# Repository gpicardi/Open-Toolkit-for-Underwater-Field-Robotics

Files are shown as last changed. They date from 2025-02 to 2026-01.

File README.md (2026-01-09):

# Open-Source Toolkit for Underwater Manipulation and Bio-inspired Robotics

## Overview

The **Open-Source Toolkit for Underwater Manipulation and Bio-inspired Robotics** is designed to facilitate the development of underwater robotic manipulators and legged systems. It provides modular, cost-effective, and open-source solutions for waterproofing, control, power management, and software integration, enabling researchers and developers to prototype and test underwater robotic systems more efficiently.

### Key Features
- **Waterproof Canisters**: Designed for Dynamixel actuators, tested up to 30m depth.
- **Control & Power Management**: Custom electronics enabling efficient underwater operations.
- **Leakage Detection System**: Early warning system for water ingress.
- **ROS 2-Based Software Stack**: Facilitates control, sensing, and actuation.
- **Open-Source Design**: Hardware and software available for community contributions.

## System Components

### 1. Underwater Robotic Joint
- Uses **Dynamixel XM430-W350** servo motors enclosed in an aluminum canister.
- Includes a **capacitive humidity sensor** and **DHT11 temperature sensor** for early leakage detection.
- Designed with **O-ring sealing** and a **pressure relief plug** to maintain internal pressure stability.

<!--![Waterproof Actuation Module](git_images/CannisterV1.JPG)-->
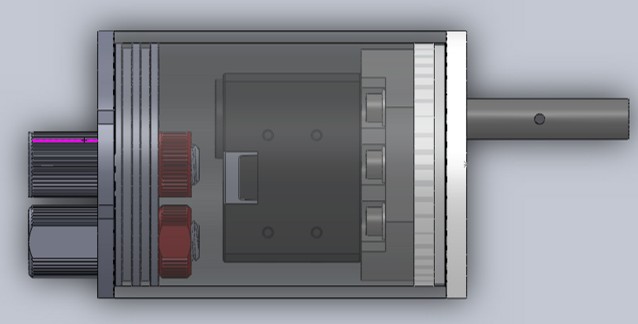
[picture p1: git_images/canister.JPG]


### 2. Control & Power Management
- Based on a **Raspberry Pi 4** architecture.
- Supports **RS485 communication** for Dynamixel servos.
- Includes **DCDC converters** for stable power delivery.
- Features integrated **humidity monitoring** for early fault detection.
- Compatible with Blue Robotics Canisters for integration.

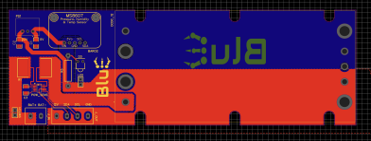
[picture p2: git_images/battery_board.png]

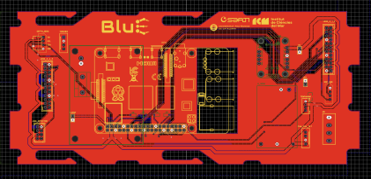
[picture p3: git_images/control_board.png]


### 3. ROS 2 Software Stack
- Modular software framework for motor control, sensing, and data acquisition.
- Supports real-time monitoring and logging.
- Facilitates integration with **networking and surface communication**.

## Experimental Validation

### 1. Leakage Detection Tests
- Humidity sensor successfully detected small water ingress during controlled tests.
- **Failure-depth tests**: Several trials conducted at different depths, with minor failures recorded at **Calabria 2021** and **La Spezia 2021**.

Leakage Detection Test

### 2. Structural and Environmental Tests
- FEM simulations in **SolidWorks** validated the canister’s buckling resistance.
- Field deployments in **real underwater conditions** for long-term monitoring.
- Potential future **hyperbaric chamber testing** to assess deeper water resistance.

Structural Testing

## Applications

### 1. **Leg Module for SILVER2**
- An **RRR serial manipulator** based on three underwater robotic joints.
- Integrated as the **legged system** for SILVER2.

SILVER2 Leg Module

### 2. **Tendon-Driven Actuation**
- Used for **soft robotic grippers** requiring flexible motion.
- Features a **spooling system** for precise cable-driven control.

Tendon-Driven Actuation

### 3. **Underactuated Mechanisms for Sampling**
- Designed for **sediment collection** in underwater environments.
- Utilizes a **four-bar linkage mechanism** for efficient grasping and storage.

Underactuated Sampling System

## Open Science & Reproducibility

To foster collaboration and reproducibility, all hardware designs, software, and datasets are shared under open licenses:
- **GitHub Repository**: [Link to repository]
- **Zenodo Archive**: [DOI for dataset & experiments]

We encourage contributions, modifications, and feedback to improve the toolkit and extend its capabilities for broader underwater robotics applications.

## Citing this Repository

If you use this toolkit in your research or project, please cite it as follows:

```
@misc{OpenFieldRoboticToolkit,
  author = {G. Picardi, S., M. Carandell, J.Aguirregomezcorta, M. Chellpurath, J. del Rio, M. Calisti, and J. Aguzzi},
  title = {Open Toolkit for Underwater Field Robotics},
  year = {2025},
  url = {[https://github.com/your-repo](https://github.com/gpicardi/Open-Toolkit-for-Underwater-Field-Robotics/)}
}
```

## Future Work
- Scaling for deeper environments beyond 30m.
- Integration of **AI-driven control strategies** for adaptive locomotion.
- Exploring bio-inspired legged movement for improved seabed interaction.
- Enhancing modularity for broader use cases in oceanographic research.

---
For more information, contact: **Giacomo Picardi giacomo.picardi1991@gmail.com or gpicardi@icm.csic.es**

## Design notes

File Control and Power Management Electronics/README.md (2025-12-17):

# Control and Power Management Electronics

## Overview

This repository documents the **control and power management electronics** design of the **Open Toolkit for Underwater Robotics**. The focus is on providing robust, modular, and efficient electronic control systems suitable for underwater robotics applications. The **Main board** folder and the **Battery board** folders respectively contain a csv file with the Bill Of Material (BOM), a pdf file with the electrical scheme, and two compressed folder with 3D and gerber files for visualization in electronics CAD and manufacturing the PCBs. Both PCBs have been dimensioned to fit into standard watertight enclosures add_dimensions (https://bluerobotics.com/store/watertight-enclosures/wte-vp/).

## Electronics and Power Management System

### 1. Control Board
- Based on **Raspberry Pi 4** architecture.
- Supports **RS485 communication** for **Dynamixel** actuators.
- Provides interface for the following sensor devices: BNO055 **IMU**, DHT11 **temperature and humidity sensors**, ltc2945 **power monitor**, DHT11 **temperature and humidity sensor**, ms8607 **external pressure sensor**.
- Provides interface for **PWM devices** such as torches, servomotors
- Supports 12V power input and it integrated a **DCDC converter** to supply **5V**

Control Board

### 2. Power Management Board
- Regulates power supply for **motors, sensors, and communication devices**.
- Supports up to **24V power input** from battery, designed to work with a 12V 25Ah DC lithium polymer battery*.
- Includes i2c line to for internal **pressure, temperature and humidity sensor MS5837** .

Power Management Board

## List of Components

| Component | Specification | Function |
|---|---|---|
| Single board computer | Raspberry Pi 4 | Controls all robotic operations |
| IMU | BNO055 | 9 DOF IMU with fused absolute orientation | Raw accelerations, angular velocities, magnetic field and fused absolute orientation
| Humidity and temperature sensor | DHT11 | Early leakage detection within control and motor canisters |
| Power monitor | LTC2945 | Monitoring Voltage, Current and Power consumption  |
| Pressure, humidity and temperature sensor | MS5837 | Early leakage detection within battery canister |
| External pressure and temperature sensing | MS8607 | External temperature and pressure for depth estimation |

## Discussion & Tips
Any other interesting point or tips for improvements can go here

## Future Improvements
Same.

---
For more information, contact: **Giacomo Picardi giacomo.picardi1991@gmail.com or gpicardi@icm.csic.es** or **Matias Carandell mail**

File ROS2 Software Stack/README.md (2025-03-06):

# ROS2 Software Stack

## Disclaimer
To be ported from BluE repository 

## Overview

This repository documents the **ROS2 Software Stack** used in the **Open Toolkit for Underwater Robotics**. The software provides modular control for underwater robotic joints, sensors, and communication interfaces, leveraging ROS2 for distributed and scalable operation.

## Software Architecture

The ROS2 software stack includes:
- **Sensor Nodes** for real-time data acquisition.
- **Motor Control and State Feedback using ros2_control** for efficient motion execution.
- **Communication Interfaces** for networked operations (e.g. with a control PC, surface buoy, or fixed platform). 

## Sensor Nodes

### 1. **Humidity and Temperature Sensor Node**
- **Sensor Used**: DHT11
- **Description**: Monitors the internal canister conditions to detect early leakage or overheating.
- **Topic Published**: `/dht11_sensor_data` (rrr_interfaces/msg/DhtSensorData)
- **Data Format**:
  ```\
  std_msgs/String location
  std_msgs/Float64 temperature
  std_msgs/Float64 humidity
  ```

### 2. **IMU Node (Inertial Measurement Unit)**
- **Sensor Used**: BNO055
- **Description**: Provides real-time orientation, acceleration, and angular velocity for state estimation.
- **Topic Published**: `/imu/data` (sensor_msgs/msg/Imu)
- **Reference Repository**: https://github.com/flynneva/bno055

### 3. **Internal Pressure, Temperature and Humidity Sensor Node**
- **Sensor Used**: MS8607
- **Description**: Measures pressure, temperature and humidity inside the control canister.
- **Topic Published**: 
  - `/ms8607/pressure` (std_msgs/Float64)
  - `/ms8607/temperature` (std_msgs/Float64)
  - `/ms8607/humidity` (std_msgs/Float64)

### 4. **External Pressure, Temperature and Depth Sensor Node**
- **Sensor Used**: MS8537
- **Description**: Measures underwater pressure, temperature and depth.
- **Topic Published**:
  - `/ms8537/pressure` (std_msgs/Float64)
  - `/ms8537/temperature` (std_msgs/Float64)
  - `/ms8537/depth` (std_msgs/Float64)

### 5. **Powering Monitor Sensor Node**
- **Sensor Used**: LTC2945
- **Description**: Measures power monitoring.
- **Topic Published**:
  - `/ltc2945/vin` (std_msgs/Float64)
  - `/ltc2945/power` (std_msgs/Float64)
  - `/ltc2945/current` (std_msgs/Float64)

## Motor Control with `ros2_control`

The **ros2_control** framework is used for real-time motor actuation.

### 1. **Hardware Interface**
- **Driver Used**: Dynamixel Workbench (RS485 communication) https://github.com/dynamixel-community/dynamixel_hardware.
- **XML RRR_Manipulator Xacro File**: Simple transmission mechanism added to set offset and reduction of the Dynamixel Actuators
```xml
<transmission name="coxa_transmission">
  <plugin>transmission_interface/SimpleTransmission</plugin>
  <actuator name="coxa_actuator" role="coxa_actuator"/>
  <joint name="coxa_joint" role="coxa_joint">
      <mechanical_reduction>${coxa_reduction}</mechanical_reduction>
      <offset>${coxa_offset}</offset>
  </joint>
</transmission>
```
### 2. **Controller Configuration**
A sample `ros2_control` configuration for the motor driver:
```yaml
controller_manager:
  ros__parameters:
    update_rate: 30

    joint_state_broadcaster:
      type: joint_state_broadcaster/JointStateBroadcaster

    forward_position_controller:
      type: forward_command_controller/ForwardCommandController

    joint_trajectory_position_controller:
      type: joint_trajectory_controller/JointTrajectoryController

forward_position_controller:
  ros__parameters:
    joints:
      - coxa_joint
      - femur_joint
      - tibia_joint

    interface_name: position

    action_monitor_rate: 20.0

    allow_partial_joints_goal: false
    open_loop_control: true
    allow_integration_in_goal_trajectories: true
    constraints:
      stopped_velocity_tolerance: 0.01
      goal_time: 0.0

```

### 3. **Motor Control Execution**
- Position commands are sent via `/forward_position_controller/commands`. I.e.:
  ```
  ros2 topic pub --once /forward_position_controller/commands std_msgs/msg/Float64MultiArray "data: - 0.75 - 0.8 - 2.3"

  ros2 topic pub --once /forward_position_controller/commands std_msgs/msg/Float64MultiArray "{data:  [2.0, 2.0, 2.0]}"
  ```
- Position-based control can be implemented via `/motor/position`.
- State feedback (position, velocity, effort) is provided via `/joint_states`.

### 4. RRR Manipulator Application
- The toolkit is applied to the case of an RRR serial manipulator.
- Robot description and controller configuration are contained in the /rrr_manipulator package.
- Replace such directory with your own description in order to test your own robot implementation.
---
For more information, contact:
- **Giacomo Picardi: giacomo.picardi1991@gmail.com or gpicardi@icm.csic.es**
- **Jorge Aguirregomezcorta Aina: jaguirregomezcorta@gmail.com or jaguirregomezcorta@icm.csic.es**

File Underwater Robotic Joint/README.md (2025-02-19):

# Underwater Robotics joint

## Overview

This repository documents the mechanical design of the **Open Toolkit for Underwater Robotics**, providing details on the waterproof canisters, actuator integration, and material selection. The goal is to offer a reproducible, modular, and cost-effective approach to underwater robotic systems.

## Mechanical Subsystems

### 1. Waterproof Actuation Module
- Designed for **Dynamixel XM430-W350** actuators.
- Enclosed in a **6000-series aluminum** canister for corrosion resistance.
- Features a **double O-ring seal** and **pressure relief plug**.
- Includes **early leakage detection** with humidity and temperature sensors.



### 2. Structural Components
- Frame and mounting brackets designed for **submersion stability**.
- Components are **CNC machined** for precision.
- Stress analysis performed using **FEM simulations** in SolidWorks.

## Material Selection

| Component | Material | Justification |
|---|---|---|
| Canister | 6000-series Aluminum | Corrosion resistance, lightweight, machinable |
| Shaft | 316 Stainless Steel  | Prevents corrosion under prolonged exposure |
| Seals | Nitrile Rubber (NBR) | High resistance to water ingress |
| Front Cap | ABS Plastic | Good adhesion properties with aluminum |
| Structural Frame  | Anodized Aluminum | Increased durability in marine environments  |

## Discussion & Tips

### 1. **Canister Sealing Considerations**
- Ensure **O-rings are lubricated** before assembly.
- Avoid excessive tightening of **rear cap** to maintain proper compression.
- Periodically inspect the **humidity sensor readings** for early leakage detection.

### 2. **Structural Strength & Buoyancy**
- Consider **reducing metal thickness** to minimize weight without compromising depth resistance.
- Add **buoyancy foam** for neutral buoyancy in deeper deployments.
- FEM analysis suggests **reinforcement** at stress points in the leg modules.

### 3. **Corrosion Prevention**
- **Rinse components with fresh water** after deployment.
- Use **anodized finishes** or protective coatings on aluminum surfaces.
- Regularly inspect and replace **rubber seals** to maintain watertight integrity.

## Future Improvements
- **Optimizing shaft seals** to reduce potential lateral leaks.
- **Exploring new materials** like titanium for deeper applications.
- **Hyperbaric testing** to validate performance beyond 30m depth.

---
For more information, contact: **Giacomo Picardi giacomo.picardi1991@gmail.com or gpicardi@icm.csic.es** or **Saverio Iacoponi mail@mail**

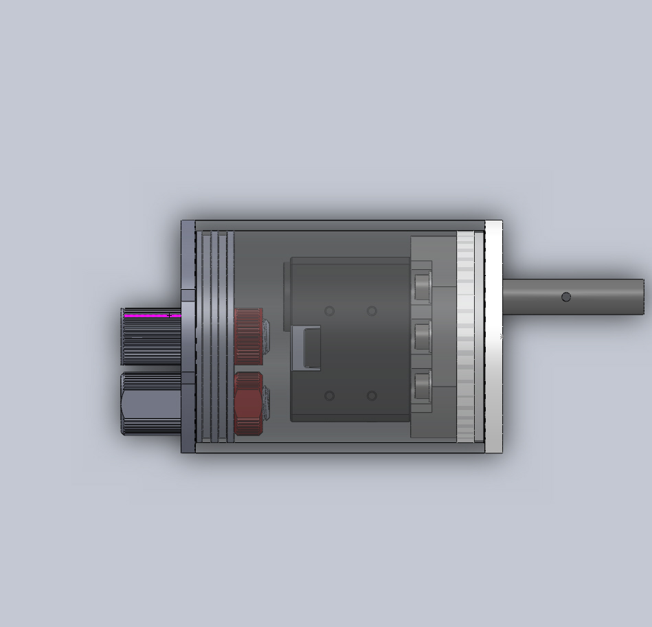
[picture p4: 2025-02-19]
git_images/CannisterV1.JPG

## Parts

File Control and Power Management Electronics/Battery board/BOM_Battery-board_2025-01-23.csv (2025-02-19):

ID | Name | Designator | Footprint | Quantity | Manufacturer Part | Manufacturer | Supplier | Supplier Part | Price | Pins | 3DModel | Contributor | JLCPCB Part Class | Package Display | description | link
1 | V28A12C200BL | DCDC_12 | V48A24C500BG | 1 |  |  |  |  |  | 9 |  | Simon
2 | 3mΩ | R1 | RES-SMD_L15.0-W7.7 | 1 | PU5931FKMP70R001L | YAGEO(国巨) | LCSC | C2079813 | 0.308 | 2 | RES-SMD_L15.0-W7.7 | lcsc | Extended Part |  |  | https://lcsc.com/eda_search?q=C2079813&%26type=1&ref=editor
3 | 173010542 | PS1 | 173010542 | 1 |  |  |  |  |  | 3 |  | FelipeRifo
4 | ADAFRUIT MS8607 PRESSURE HUMIDIT - edited | BARO2 | ADAFRUIT MS8607 | 1 | 4716 | Adafruit Industries LLC | Digi-Key | 1528-4716-ND |  | 7 |  | daniyal.ah3 |  |  |  | https://www.digikey.pt/products/en?keywords=%E2%80%8E1528-4716-ND%E2%80%8E
5 | 10uF | C1,C2 | 1206 | 2 | C1206C106K4RACAUTO | KEMET | LCSC | C141190 | 0.129 | 2 |  | LCSC |  | No
6 | 0.1uF | C3 | 1206 | 1 | C1206C106K4RACAUTO | KEMET | LCSC | C141190 | 0.129 | 2 |  | LCSC |  | No
7 | LED-1 | D3 | LED-TH_LED-DP2-2LED | 1 | 5600 | VccLite | Digi-Key | L20325-ND |  | 2 |  | sifa33752 |  |  |  | https://vcclite.com/product/5602f5-5v/
8 | DINKLE RHB02 | J_IN | DINKLE 2 PIN_2 | 1 | 2EHDR-02P | Dinkle | LCSC | C183509 |  | 2 |  | corykersey |  |  |  | https://lcsc.com/product-detail/Terminal-Blocks_2EHDR-02P_C183509.html
9 | NO | J_OUT | DINKLE 4 PIN_2 | 1 | 2EHDR-06P |  | LCSC | C165061 |  | 4 |  | corykersey |  |  |  | https://lcsc.com/product-detail/Terminal-Blocks_2EHDR-06P_C165061.html
10 | jumper | LED,SWITCH | JUMPER2 | 2 |  |  |  | MAX9934 |  | 2 |  | Matias Carandell |  |  | Jumper 2 Pin
11 | LTC2945IMS#TRPBF | POW_SENS | MSOP-12_L4.0-W3.0-P0.65-LS5.0-BL | 1 | LTC2945IMS#TRPBF | ADI(亚德诺)/LINEAR(凌特) | LCSC | C683689 | 7.671 | 12 | MSOP-12_L4.0-W3.0-H1.1-P0.65-LS4.9-BL | LCSC | Extended Part |  |  | https://lcsc.com/eda_search?q=C683689&%26type=1&ref=editor
12 | RESISTOR 5W | R3 | RESISTOR 2W | 1 |  |  |  |  |  | 2 |  | surajp1977

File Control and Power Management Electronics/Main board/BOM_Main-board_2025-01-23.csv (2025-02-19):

ID | Name | Designator | Footprint | Quantity | Manufacturer Part | Manufacturer | Supplier | Supplier Part | Price | Pins | 3DModel | Contributor | JLCPCB Part Class | Package Display | description | link
1 | 4PIN | TEMP&HUM1,TEMP&HUM2,TEMP&HUM3,TEMP&HUM4,TEMP&HUM6,TEMP&HUM7,TEMP&HUM5 | GROVE-2MM-4PIN-A/D | 7 |  |  |  | MAX9934 |  | 4 |  | Matias Carandell
2 | BM04B- | DEPTH_SENS | HUM_SENS2 | 1 | BM04B-GHS-TBT(LF)(SN) | JST | LCSC | C161692 | 0.169 | 10 |  | LCSC | Extended Part |  |  | https://lcsc.com/eda_search?q=C161692&%26type=1&ref=editor
3 | ADAFRUIT 9-DOF | IMU | ADAFRUIT BNO055 | 1 | Solid State Relays | Crydom | Adafruit |  |  | 14 |  | Daniel Sánchez
4 | TRACO POWER THM 15WI | DCDC_5 | TRACO POWER THM 15WI | 1 |  |  |  |  |  | 5 |  | longDiscoStick
5 | jumper | POW_DEPTH,POW_T&H,3.3RSP,J2,J4,J5,POW_IMU,POW_LEG,POW_TORCH | JUMPER2 | 9 |  |  |  | MAX9934 |  | 2 |  | Matias Carandell |  |  | Jumper 2 Pin
6 | 5PIN | IMU_SEL | 5PIN | 1 |  |  |  | MAX9934 |  | 5 |  | Matias Carandell
7 | NO | R1,R2,R3,R4 | RESISTOR-SMD-1206 | 4 |  |  | Banggood |  |  | 2 |  | WalterHaazen
8 | DINKLE RHB02 | J3,J1,J6 | DINKLE 2 PIN_2 | 3 | 2EHDR-02P | Dinkle | LCSC | C183509 |  | 2 |  | corykersey |  |  |  | https://lcsc.com/product-detail/Terminal-Blocks_2EHDR-02P_C183509.html
9 | 4PIN | SPI_SEL,I2C1_SEL,I2C2_SEL,TORCHES | TXRX | 4 |  |  |  | MAX9934 |  | 4 |  | Matias Carandell
10 | 22-03-5045 MOLEX | L2,L3,L4,L5,L6,L1,RSP_USB | MOLEX_22-03-5045 | 7 |  |  |  |  |  | 4 |  | Matias Carandell
11 | 3PIN | POW_BARO,PWM_TORCH | 3PIN | 2 |  |  |  | MAX9934 |  | 3 |  | Matias Carandell
12 | ADAFRUIT MS8607 PRESSURE HUMIDIT - edited | BARO1 | ADAFRUIT MS8607 | 1 | 4716 | Adafruit Industries LLC | Digi-Key | 1528-4716-ND |  | 7 |  | daniyal.ah3 |  |  |  | https://www.digikey.pt/products/en?keywords=%E2%80%8E1528-4716-ND%E2%80%8E
13 | 10uF | C1 | 1206 | 1 | C1206C106K4RACAUTO | KEMET | LCSC | C141190 | 0.129 | 2 |  | LCSC |  | No
14 | 8PIN | SIG_SEL,SIG_SEL2 | 8PIN | 2 |  |  |  | MAX9934 |  | 8 |  | Matias Carandell
15 | DINKLE RHB08 | JIN | DINKLE 4 PIN_2 | 1 | 2EHDR-06P |  | LCSC | C165061 |  | 4 |  | corykersey |  |  |  | https://lcsc.com/product-detail/Terminal-Blocks_2EHDR-06P_C165061.html
16 | RASPBERRY_PI_4_MODEL_B COPY | RPI1 | RASPBERRY_PI_4_MODEL_B | 1 | 2.54mm 2*20PFemale header | BOOMELE | LCSC | C50982 | 0.215 | 40 | HDR-TH_40P-P2.54-F-LI-2X20P | engeltronics | Extended Part
17 | CC6-2405SF-E | DCDC_3 | CC6-XXXXXF-E | 1 |  |  |  |  |  | 9 |  | Carlos Schelim

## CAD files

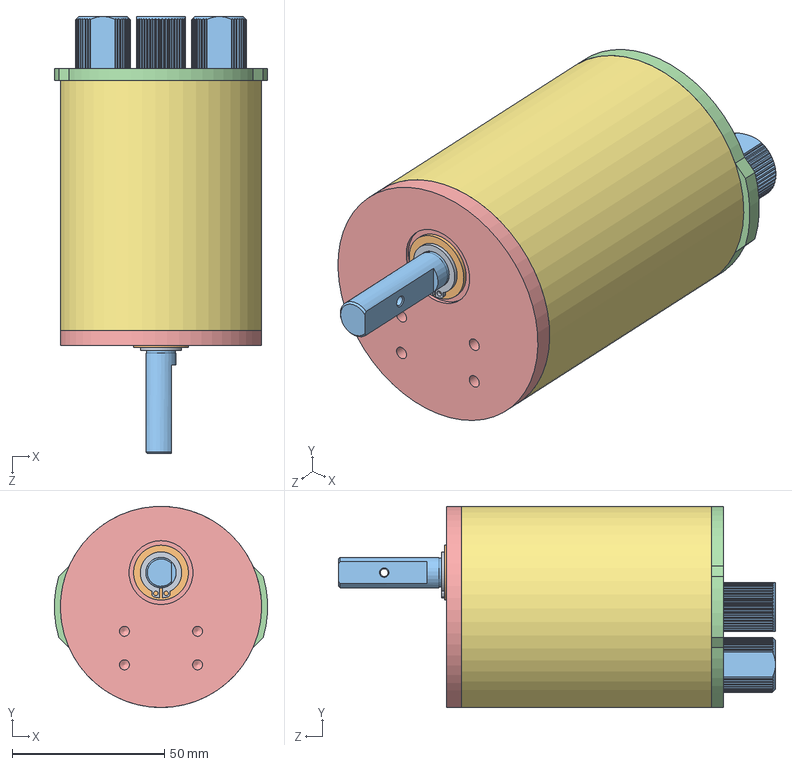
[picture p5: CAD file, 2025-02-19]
Underwater Robotic Joint/UW Robotic Joint Assembly SolidWorks/CannisterV1_new_version.SLDASM
69.9 x 66.0 x 143.4 mm
X-430_SPACER_RING x 8
X-430_CVR_CABLE
albero 2
mortor attachment
M2o5x10 x 2
M2o5x20 x 4
cannister cylinder
rondella M4 x 6
tappo frontale
tappo contatti
Penetrator 8mm x 3
WTM 1018 010
retention_ring_10mm

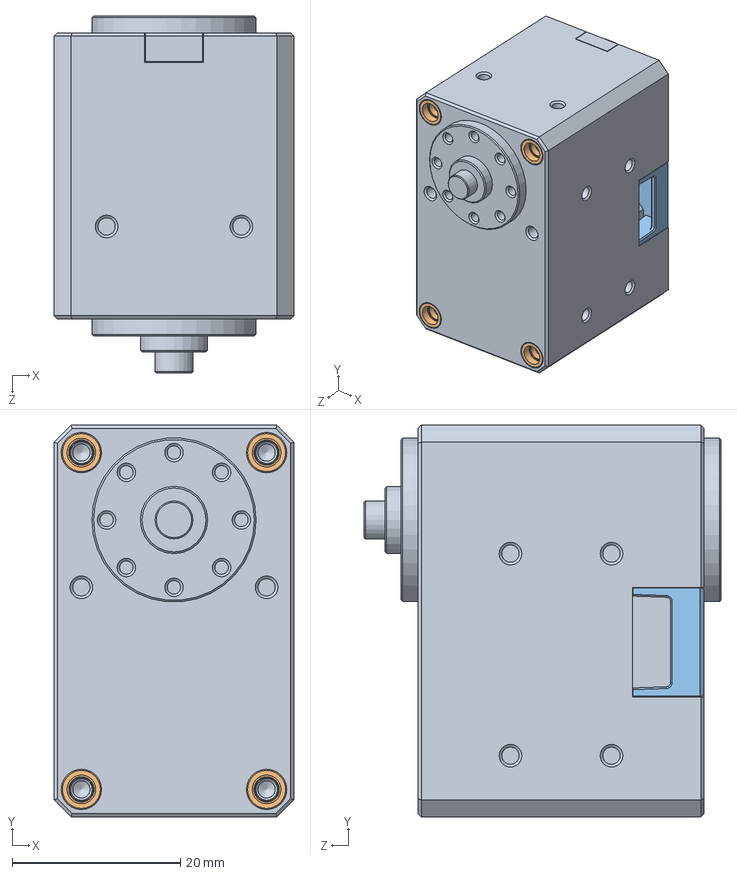
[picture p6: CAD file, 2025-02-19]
Underwater Robotic Joint/UW Robotic Joint Assembly SolidWorks/X-430_IDLE_20160516_ASM.sldasm
28.5 x 46.5 x 42.4 mm
X-430_IDLE
X-430_SPACER_RING x 8
X-430_CVR_CABLE

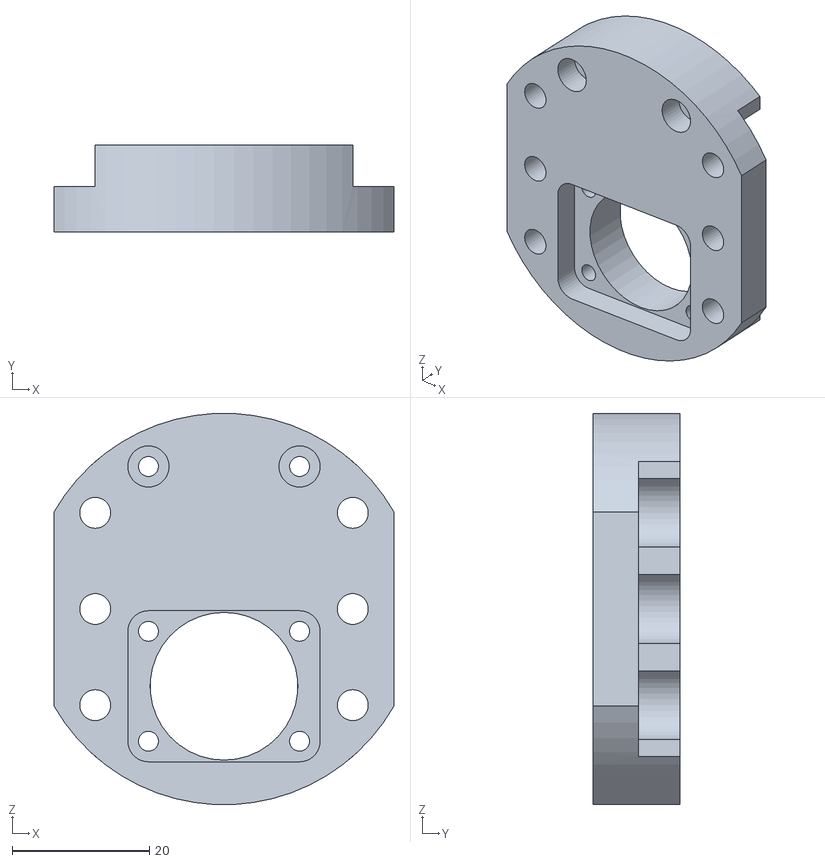
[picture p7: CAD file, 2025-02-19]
Underwater Robotic Joint/Underwater Robotic Joint Files for Manufacturing/mortor attachment.STL
49.5 x 12.6 x 56.9

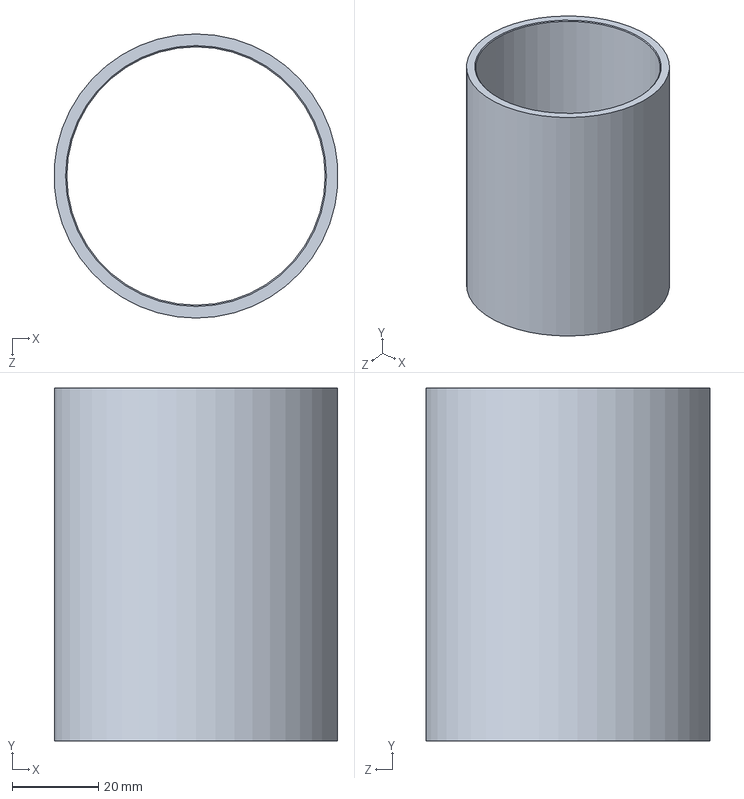
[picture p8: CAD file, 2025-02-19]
Underwater Robotic Joint/UW Robotic Joint Assembly SolidWorks/cannister cylinder.SLDPRT
65.8 x 82.0 x 66.0 mm

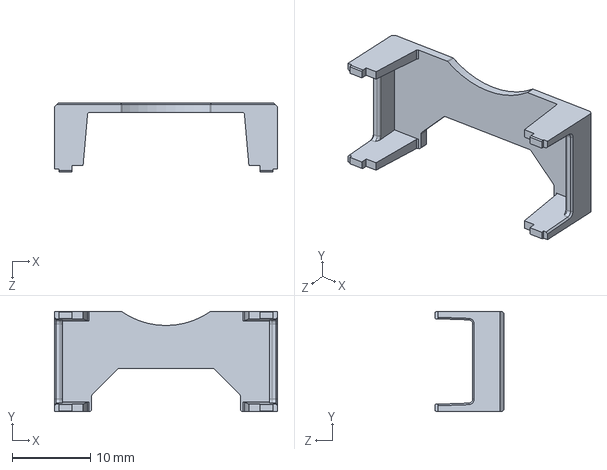
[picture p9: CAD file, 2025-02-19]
Underwater Robotic Joint/UW Robotic Joint Assembly SolidWorks/X-430_CVR_CABLE.sldprt
28.5 x 12.8 x 8.80 mm

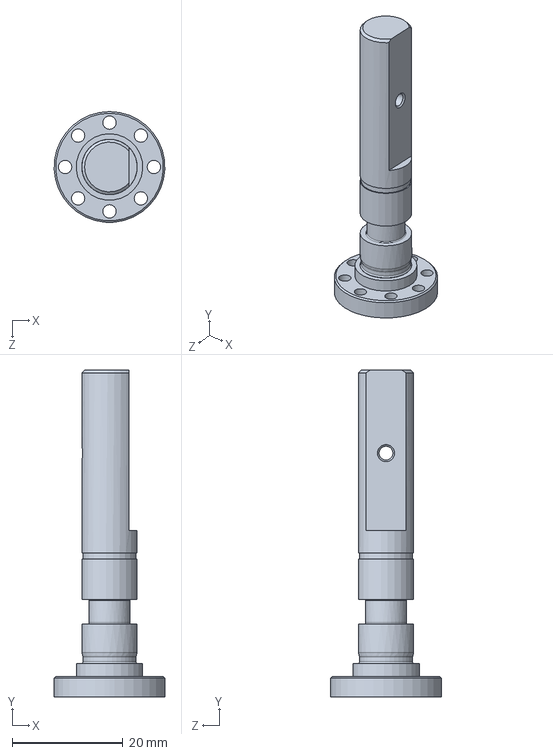
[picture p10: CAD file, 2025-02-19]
Underwater Robotic Joint/UW Robotic Joint Assembly SolidWorks/albero 2.SLDPRT
20.0 x 59.0 x 20.0 mm

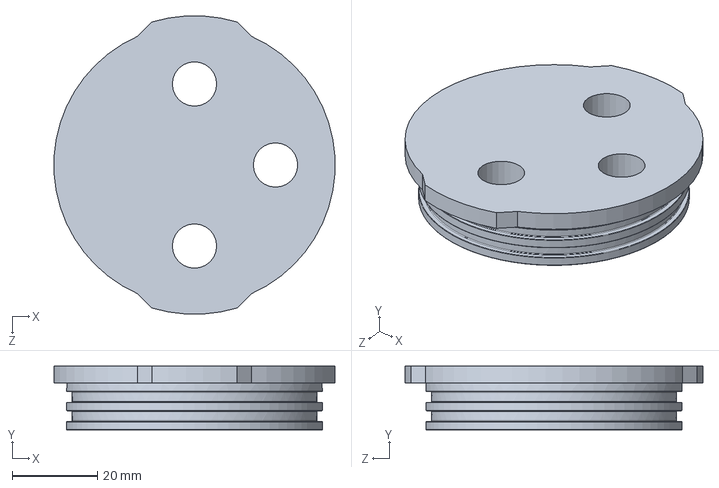
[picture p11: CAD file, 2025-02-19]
Underwater Robotic Joint/UW Robotic Joint Assembly SolidWorks/tappo contatti.SLDPRT
65.9 x 15.0 x 69.9 mm

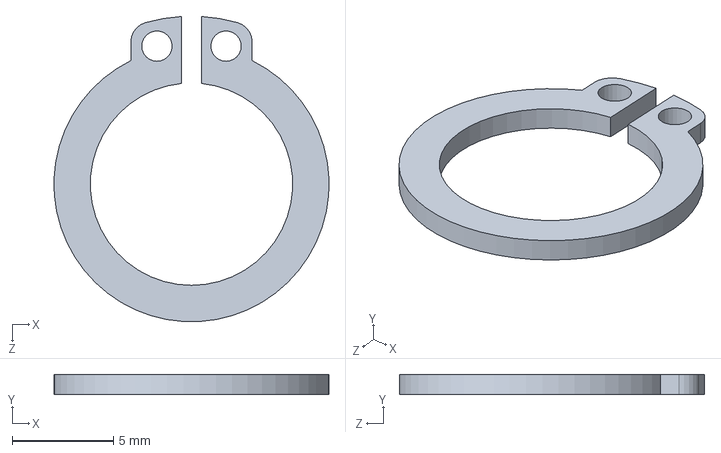
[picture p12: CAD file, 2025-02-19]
Underwater Robotic Joint/UW Robotic Joint Assembly SolidWorks/retention_ring_10mm.SLDPRT
13.6 x 1.00 x 15.1 mm

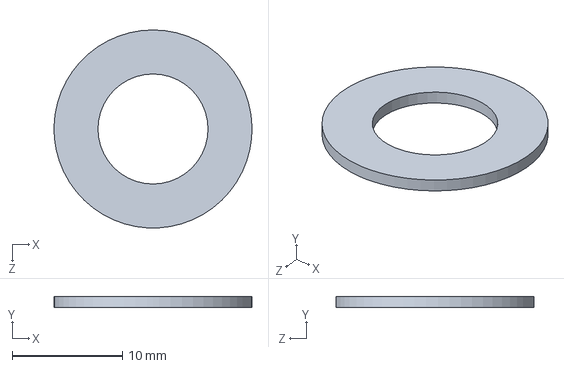
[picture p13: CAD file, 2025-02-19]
Underwater Robotic Joint/UW Robotic Joint Assembly SolidWorks/WTM 1018 010.SLDPRT
18.0 x 1.00 x 18.0 mm

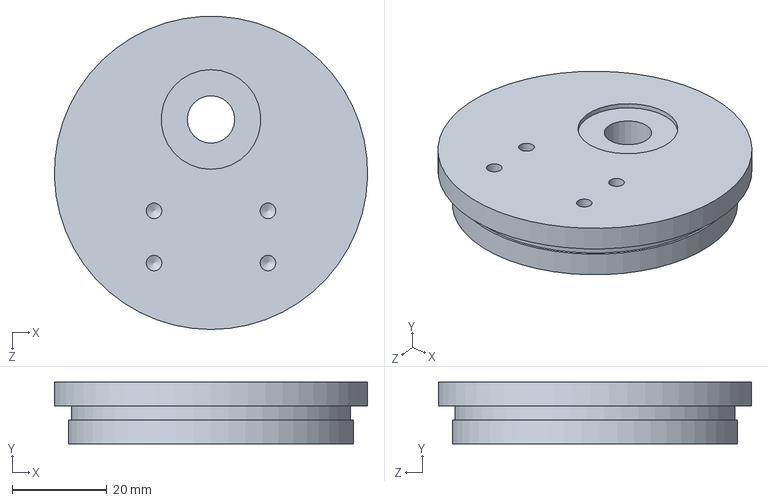
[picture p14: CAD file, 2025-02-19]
Underwater Robotic Joint/UW Robotic Joint Assembly SolidWorks/tappo frontale.SLDPRT
66.0 x 13.0 x 65.9 mm

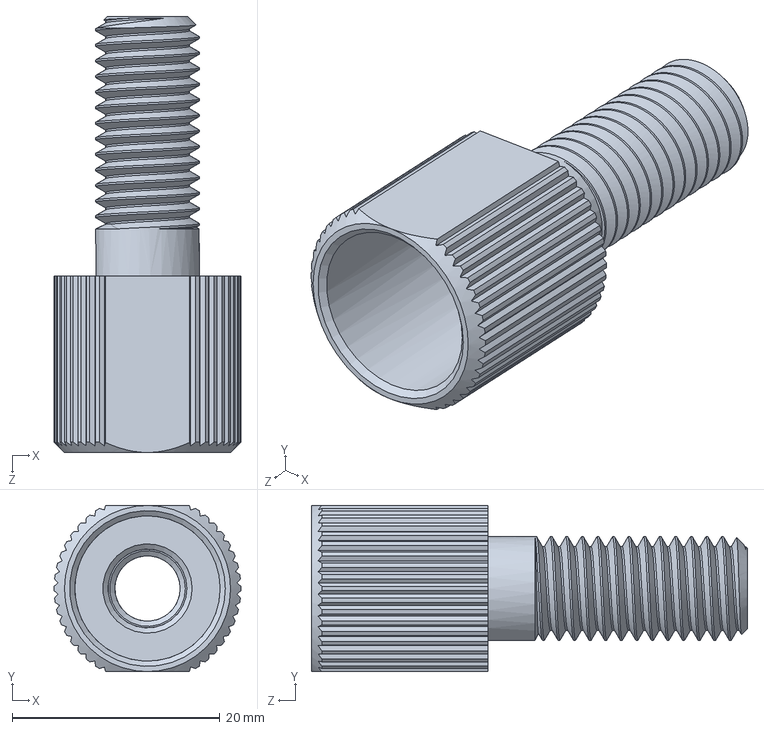
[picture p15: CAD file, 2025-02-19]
Underwater Robotic Joint/UW Robotic Joint Assembly SolidWorks/Penetrator 8mm.SLDPRT
18.0 x 16.0 x 42.0 mm

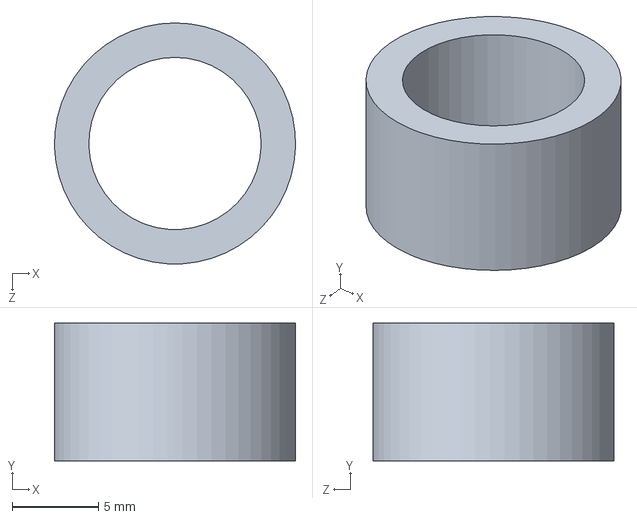
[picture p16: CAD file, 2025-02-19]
Underwater Robotic Joint/UW Robotic Joint Assembly SolidWorks/bronzina m10.SLDPRT
14.0 x 8.00 x 14.0 mm

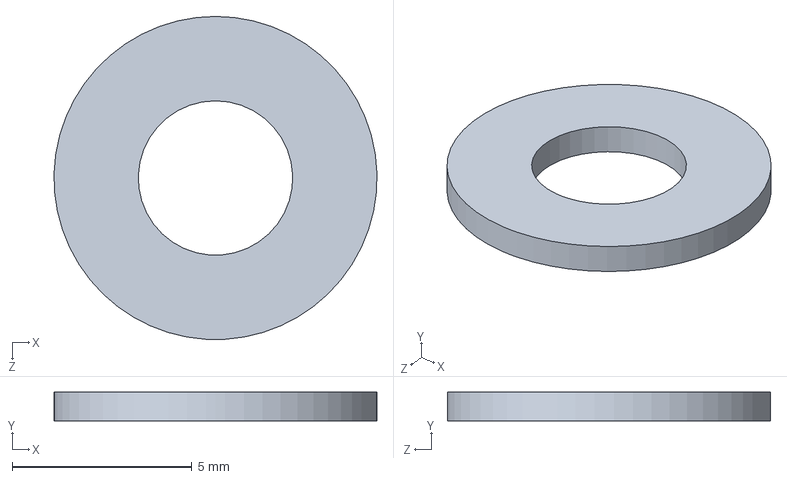
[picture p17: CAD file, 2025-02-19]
Underwater Robotic Joint/UW Robotic Joint Assembly SolidWorks/rondella M4.SLDPRT
9.00 x 0.8 x 9.00 mm

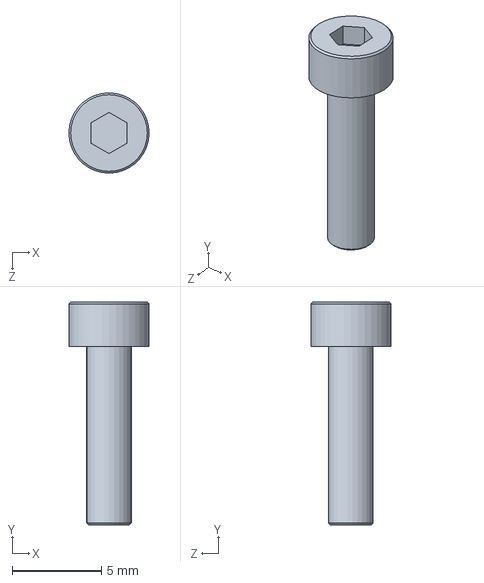
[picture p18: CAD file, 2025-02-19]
Underwater Robotic Joint/UW Robotic Joint Assembly SolidWorks/M2o5x10.SLDPRT
4.50 x 12.5 x 4.50 mm

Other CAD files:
Underwater Robotic Joint/UW Robotic Joint Assembly SolidWorks/X-430_IDLE.sldprt
Underwater Robotic Joint/UW Robotic Joint Assembly SolidWorks/M2o5x20.SLDPRT
Underwater Robotic Joint/UW Robotic Joint Assembly SolidWorks/mortor attachment.SLDPRT
Underwater Robotic Joint/UW Robotic Joint Assembly SolidWorks/X-430_SPACER_RING.sldprt
Underwater Robotic Joint/UW Robotic Joint Assembly SolidWorks/M2x5.SLDPRT
Underwater Robotic Joint/UW Robotic Joint Assembly SolidWorks/M4x16.SLDPRT
Underwater Robotic Joint/UW Robotic Joint Assembly SolidWorks/Penetrator nut.SLDPRT
Underwater Robotic Joint/UW Robotic Joint Assembly SolidWorks/molla a tazza misumi 123020123007.SLDPRT
Underwater Robotic Joint/UW Robotic Joint Assembly SolidWorks/penetratore2.SLDPRT

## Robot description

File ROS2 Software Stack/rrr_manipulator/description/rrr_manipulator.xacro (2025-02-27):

<?xml version="1.0"?>
<robot xmlns:xacro="http://www.ros.org/wiki/xacro" name="robot">

    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
    <xacro:arg name="sim_mode" default="false"/>
     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
    <xacro:include filename="inertial_macros.xacro"/>
    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
    <xacro:include filename="rrr_manipulator_constants.xacro"/>
    
    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
    <link name = "world"></link>

    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
    <joint name="body_joint" type="fixed">
        <origin xyz="0.0 0.0 ${body_link_height}" rpy="0.0 0.0 0.0"/>
        <parent link="world"/>
        <child link="body_link"/>
    </joint>

    <link name="body_link">
        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
        <xacro:inertial_box mass="${body_link_mass}" x="${body_link_x_dim}" y ="${body_link_y_dim}" z="${body_link_z_dim}">
            <origin xyz="0.0 0 0.0"/>
        </xacro:inertial_box>
    </link>

    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
    <joint name="coxa_joint" type="revolute">
        <origin xyz="${Ox} ${Oy} ${Oz}" rpy="0.0 0.0 0.0"/>
        <parent link="body_link"/>
        <child link="coxa_link"/>
        <limit effort="100" velocity="100.0" lower="-3.14" upper="3.14" />
        <axis xyz="0 0 1"/>
        <dynamics damping="0.7"/>
    </joint>

    <link name="coxa_link">
        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
        <xacro:inertial_cylinder mass="${coxa_link_mass}" length="${coxa_link_length}" radius="${coxa_link_radius}">
            <origin xyz="${coxa_link_Ox} ${coxa_link_Oy} ${coxa_link_Oz}" rpy="0.0 ${coxa_link_Ry} 0.0"/>
        </xacro:inertial_cylinder>
    </link>

    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
    <joint name="femur_joint" type="revolute">
        <origin xyz="${femur_joint_Ox} ${femur_joint_Oy} ${femur_joint_Oz}" rpy="0.0 ${femur_joint_Ry} 0.0"/>
        <parent link="coxa_link"/>
        <child link="femur_link"/>
        <limit effort="100" velocity="100.0" lower="-3.14" upper="3.14" />
        <axis xyz="0 0 1"/>
        <dynamics damping="0.7"/>
    </joint>

    <link name="femur_link">
        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
        <xacro:inertial_box mass="${femur_link_mass}" x="${femur_link_dx}" y="${femur_link_dy}" z='${femur_link_dz}'>
            <origin xyz="${femur_link_Ox} 0.0 0.0" rpy="0.0 0.0 0.0"/>
        </xacro:inertial_box>
    </link>

    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
    <joint name="tibia_joint" type="revolute">
        <origin xyz="${tibia_joint_Ox} ${tibia_joint_Oy} ${tibia_joint_Oz}" rpy="0.0 0.0 0.0"/>
        <parent link="femur_link"/>
        <child link="tibia_link"/>
        <limit effort="100" velocity="100.0" lower="-3.14" upper="3.14" />
        <axis xyz="0 0 1"/>
        <dynamics damping="0.7"/>
    </joint>

    <link name="tibia_link">
        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
        <xacro:inertial_box mass="${tibia_link_mass}" x="${tibia_link_dx}" y="${tibia_link_dy}" z="${tibia_link_dz}">
            <origin xyz="${tibia_link_Ox} 0.0 0.0" rpy="0.0 0.0 0.0"/>
        </xacro:inertial_box>
    </link>

    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
    <ros2_control name="SilverSystem" type="system">
        <xacro:if value="$(arg sim_mode)">
            <hardware>
                <plugin>gazebo_ros2_control/GazeboSystem</plugin>
            </hardware>
        </xacro:if>
        <xacro:unless value="$(arg sim_mode)">
            <hardware>
                <plugin>dynamixel_hardware/DynamixelHardware</plugin>
                <param name="usb_port">/dev/ttyUSB0</param>
                <param name="baud_rate">1000000</param>
            </hardware>
        </xacro:unless>
    

        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
        <joint name="coxa_joint">
        <param name="id">0</param>

            <command_interface name="position">
                <param name="min">-3.14</param>
                <param name="max">3.14</param>
            </command_interface>
            
            <command_interface name="velocity"/>

            <xacro:if value="$(arg sim_mode)">
                <command_interface name="effort"/>
            </xacro:if>  

            <state_interface name="position"/>
            <state_interface name="velocity"/>
            <state_interface name="effort"/>
        </joint>

        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
        <joint name="femur_joint">
        <param name="id">1</param>

            <command_interface name="position">
                <param name="min">-3.14</param>
                <param name="max">3.14</param>
            </command_interface>

            <command_interface name="velocity"/>

            <xacro:if value="$(arg sim_mode)">
                <command_interface name="effort"/>
            </xacro:if>  

            <state_interface name="position"/>
            <state_interface name="velocity"/>
            <state_interface name="effort"/>
        </joint>

        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
        <joint name="tibia_joint">
        <param name="id">2</param>

            <command_interface name="position">
                <param name="min">-3.14</param>
                <param name="max">3.14</param>
            </command_interface>

            <command_interface name="velocity"/>

            <xacro:if value="$(arg sim_mode)">
                <command_interface name="effort"/>
            </xacro:if>  
            
            <state_interface name="position"/>
            <state_interface name="velocity"/>
            <state_interface name="effort"/>
        </joint>

        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
    </ros2_control> 
</robot>

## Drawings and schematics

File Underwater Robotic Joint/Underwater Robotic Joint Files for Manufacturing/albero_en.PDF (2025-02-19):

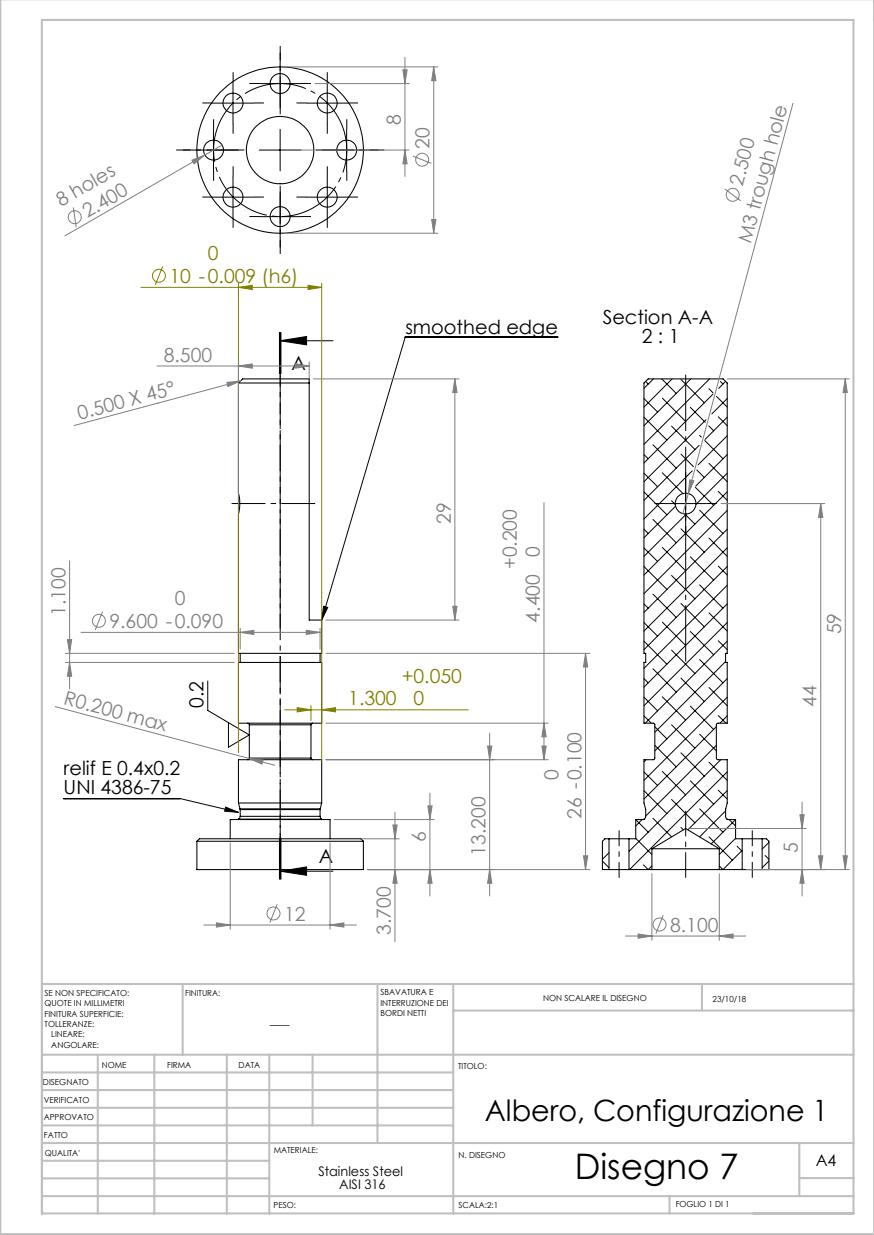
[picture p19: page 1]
8 holes; R0.200 max; relif E 0.4x0.2 UNI 4386-75; smoothed edge; M3 trough hole; Section A-A 2 : 1; SCALA:2:1; FOGLIO 1 DI 1; NON SCALARE IL DISEGNO; SBAVATURA E INTERRUZIONE DEI BORDI NETTI; SE NON SPECIFICATO:; FINITURA:

QUOTE IN MILLIMETRI
FINITURA SUPERFICIE:
TOLLERANZE:
LINEARE:
ANGOLARE:

NOME | FIRMA | DATA | | | | TITOLO: Albero, Configurazione 1
QUALITA' | | | | MATERIALE: Stainless Steel AISI 316 | Disegno 7 PESO: N. DISEGNO | A4

DISEGNATO
VERIFICATO
APPROVATO
FATTO

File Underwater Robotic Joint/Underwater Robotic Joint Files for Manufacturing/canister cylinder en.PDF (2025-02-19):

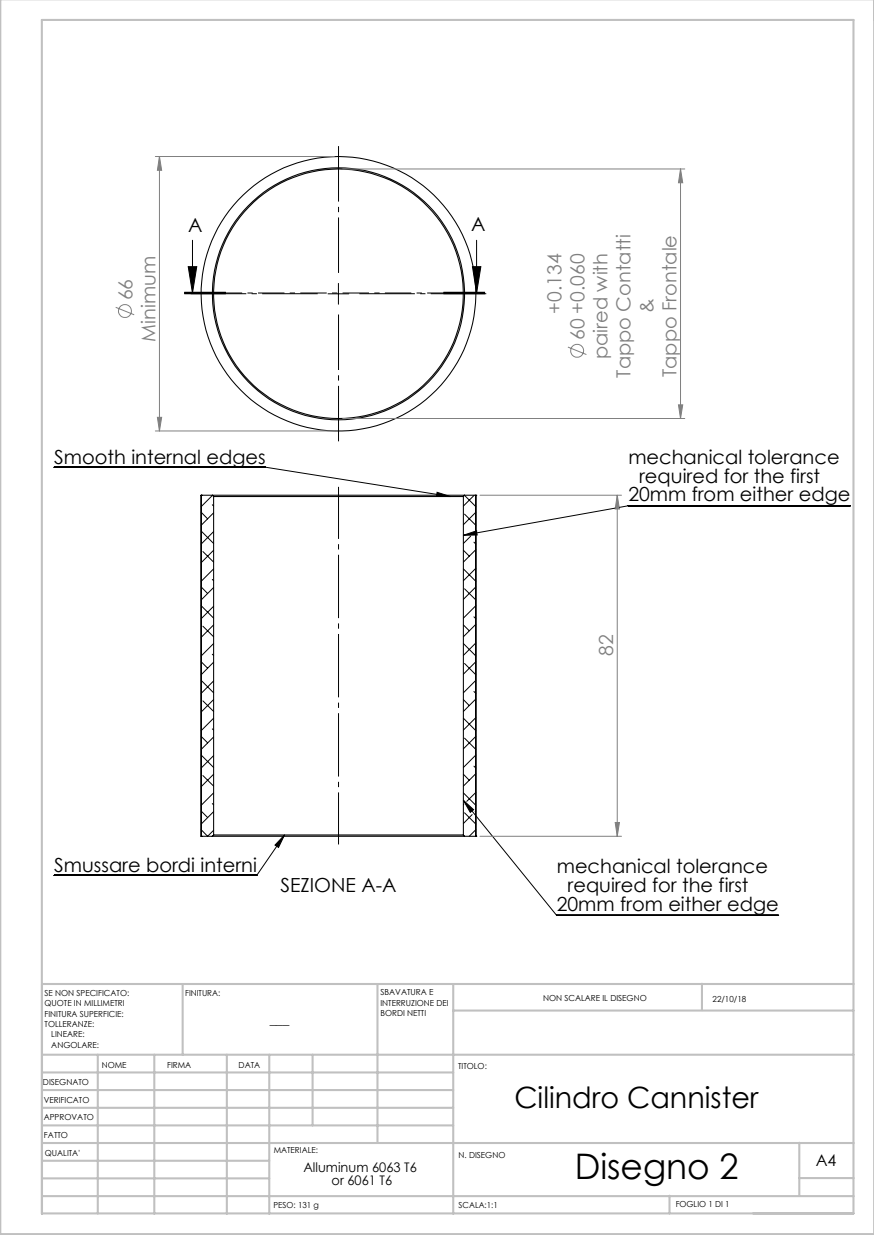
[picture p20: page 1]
paired with; Tappo Contatti; Tappo Frontale; SEZIONE A-A; PESO: 131 g; SCALA:1:1; FOGLIO 1 DI 1; NON SCALARE IL DISEGNO; SBAVATURA E INTERRUZIONE DEI BORDI NETTI; SE NON SPECIFICATO:; FINITURA:

Smooth internal edges

mechanical tolerance
required for the first
20mm from either edge

Smussare bordi interni

QUOTE IN MILLIMETRI
FINITURA SUPERFICIE:
TOLLERANZE:
LINEARE:
ANGOLARE:

NOME | FIRMA | DATA | | | | TITOLO: Cilindro Cannister
QUALITA' | | | | MATERIALE: Alluminum 6063 T6 or 6061 T6 | Disegno 2 N. DISEGNO | A4

DISEGNATO
VERIFICATO
APPROVATO
FATTO

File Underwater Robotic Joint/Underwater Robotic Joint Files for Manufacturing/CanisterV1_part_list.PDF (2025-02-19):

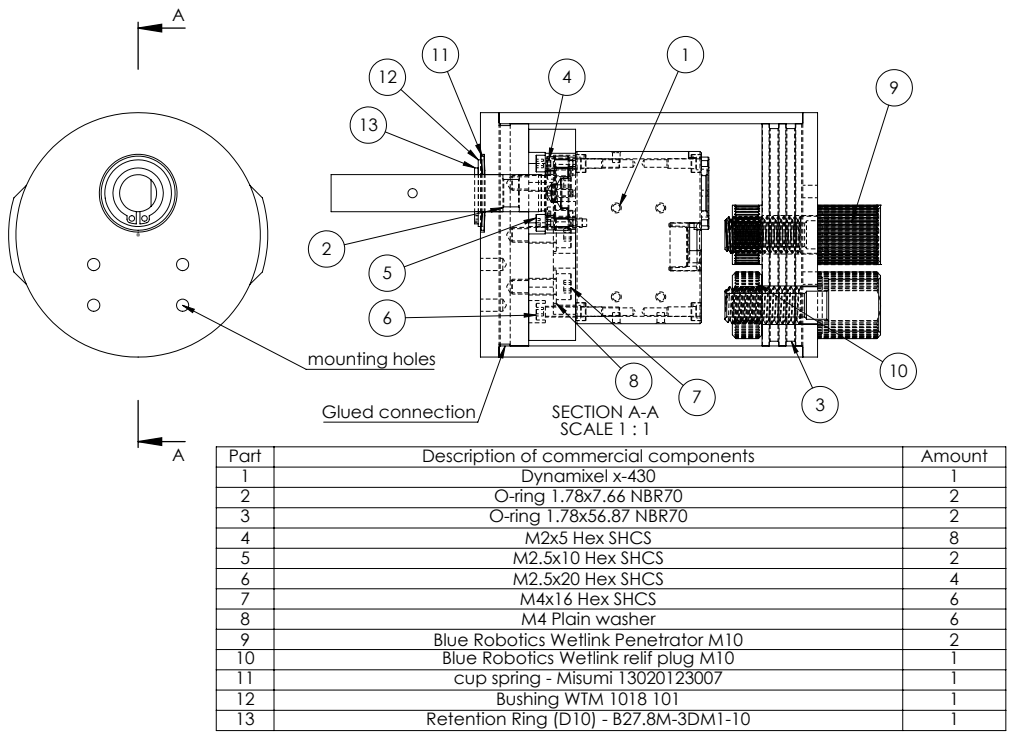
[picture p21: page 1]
SECTION A-A SCALE 1 : 1; Glued connection; mounting holes

Part | Description of commercial components | Amount
1 | Dynamixel x-430 | 1
2 | O-ring 1.78x7.66 NBR70 | 2
3 | O-ring 1.78x56.87 NBR70 | 2
4 | M2x5 Hex SHCS | 8
5 | M2.5x10 Hex SHCS | 2
6 | M2.5x20 Hex SHCS | 4
7 | M4x16 Hex SHCS | 6
8 | M4 Plain washer | 6
9 | Blue Robotics Wetlink Penetrator M10 | 2
10 | Blue Robotics Wetlink relif plug M10 | 1
11 | cup spring - Misumi 13020123007 | 1
12 | Bushing WTM 1018 101 | 1
13 | Retention Ring (D10) - B27.8M-3DM1-10 | 1

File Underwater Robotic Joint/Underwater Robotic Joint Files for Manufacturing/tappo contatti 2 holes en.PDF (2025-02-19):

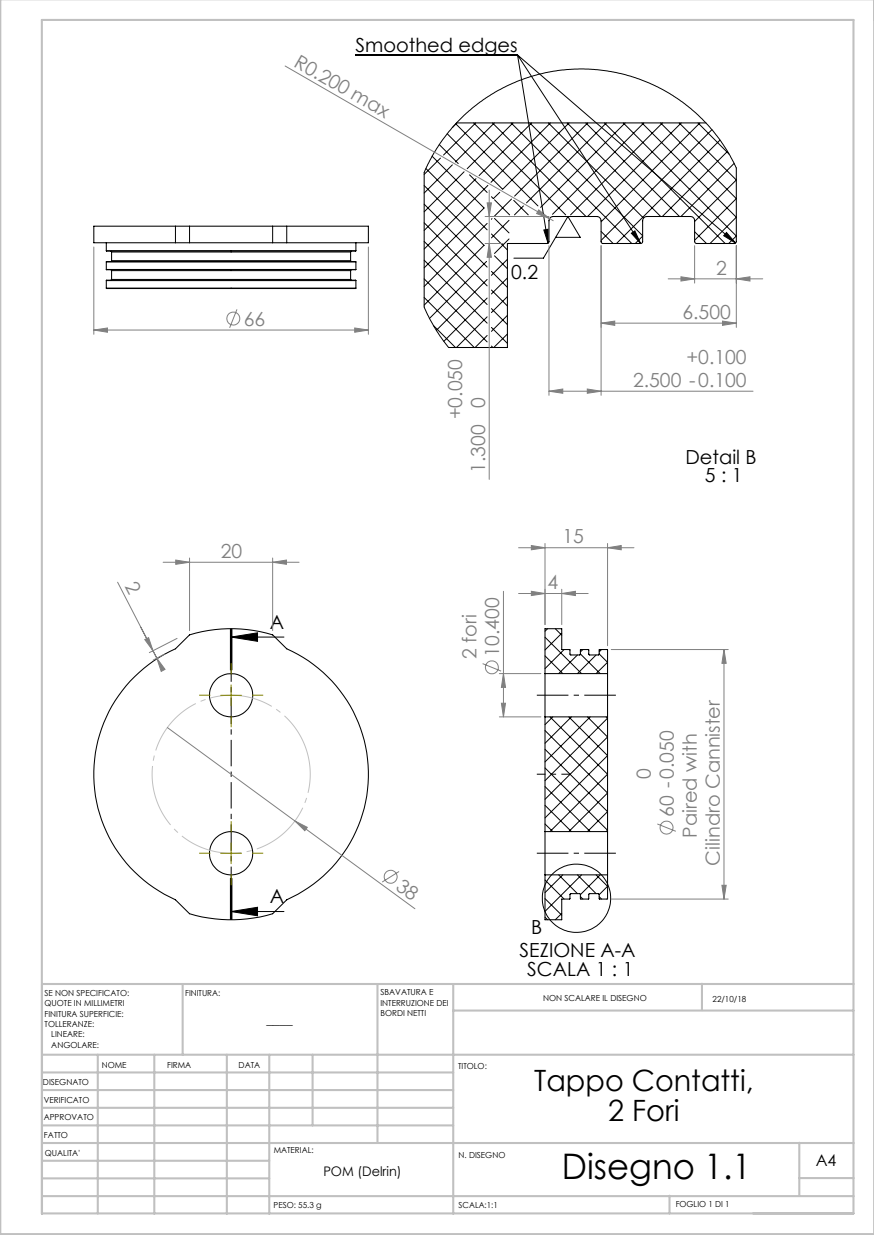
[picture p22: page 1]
Paired with; Cilindro Cannister; 2 fori; SEZIONE A-A SCALA 1 : 1; R0.200 max; Detail B 5 : 1; Smoothed edges; PESO: 55.3 g; SCALA:1:1; FOGLIO 1 DI 1; NON SCALARE IL DISEGNO; SBAVATURA E INTERRUZIONE DEI BORDI NETTI; SE NON SPECIFICATO:; FINITURA:

QUOTE IN MILLIMETRI
FINITURA SUPERFICIE:
TOLLERANZE:
LINEARE:
ANGOLARE:

NOME | FIRMA | DATA | | | | TITOLO: Tappo Contatti, 2 Fori
QUALITA' | | | | MATERIAL: POM (Delrin) | Disegno 1.1 N. DISEGNO | A4

DISEGNATO
VERIFICATO
APPROVATO
FATTO

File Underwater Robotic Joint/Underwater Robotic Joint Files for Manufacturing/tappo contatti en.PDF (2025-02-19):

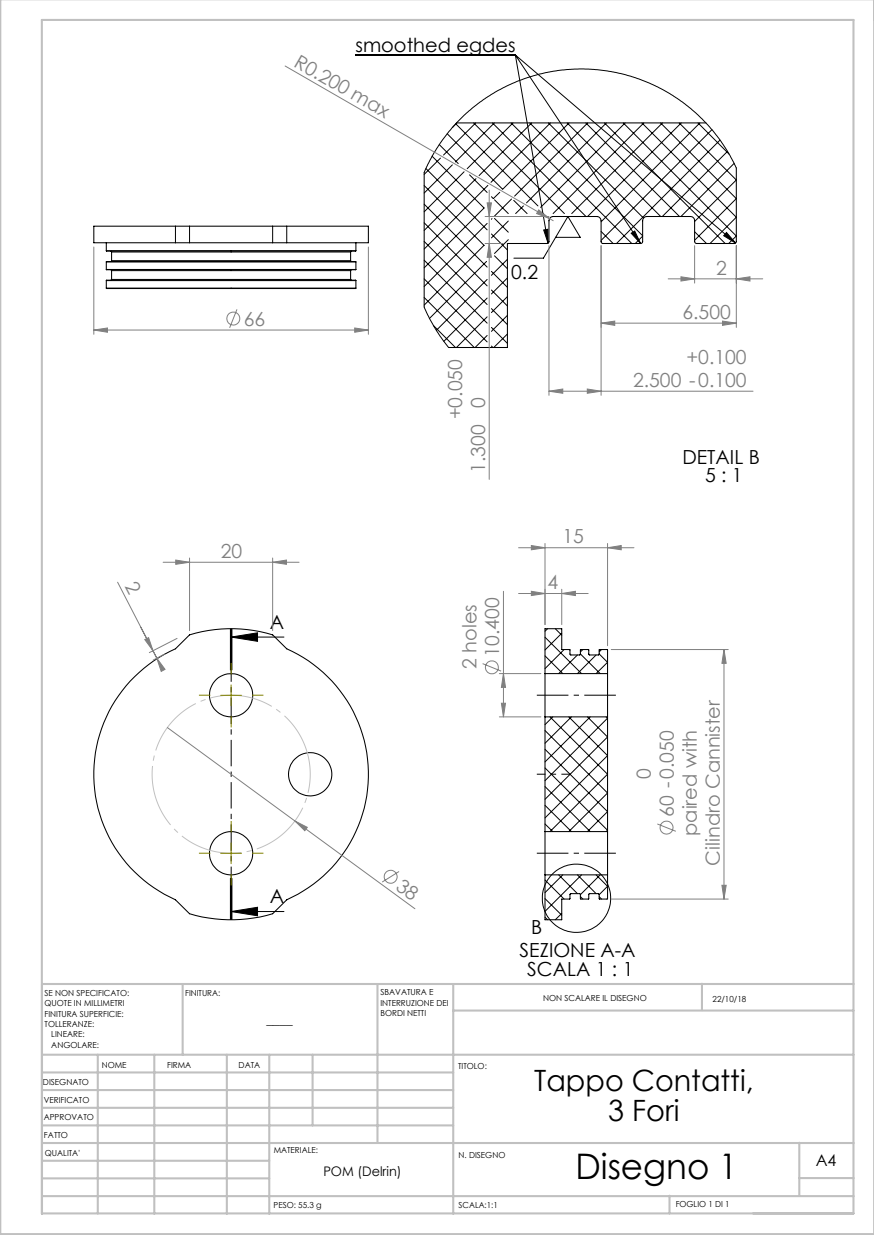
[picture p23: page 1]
paired with; Cilindro Cannister; 2 holes; SEZIONE A-A SCALA 1 : 1; R0.200 max; DETAIL B 5 : 1; smoothed egdes; PESO: 55.3 g; SCALA:1:1; FOGLIO 1 DI 1; NON SCALARE IL DISEGNO; SBAVATURA E INTERRUZIONE DEI BORDI NETTI; SE NON SPECIFICATO:; FINITURA:

QUOTE IN MILLIMETRI
FINITURA SUPERFICIE:
TOLLERANZE:
LINEARE:
ANGOLARE:

NOME | FIRMA | DATA | | | | TITOLO: Tappo Contatti, 3 Fori
QUALITA' | | | | MATERIALE: POM (Delrin) | Disegno 1 N. DISEGNO | A4

DISEGNATO
VERIFICATO
APPROVATO
FATTO

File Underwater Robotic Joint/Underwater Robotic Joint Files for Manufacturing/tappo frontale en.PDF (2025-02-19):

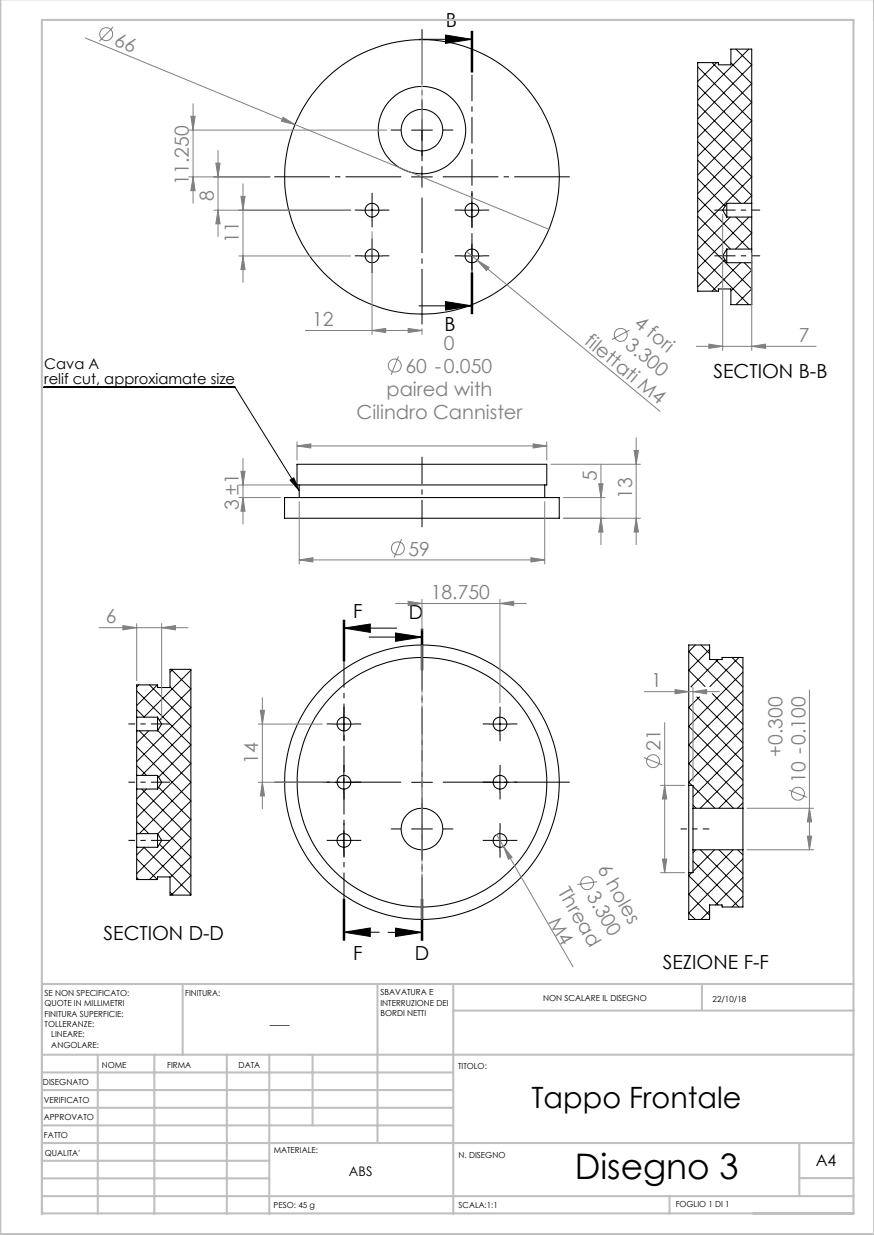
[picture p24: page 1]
6 holes; 60 -0.050 paired with Cilindro Cannister; filettati M4; 4 fori; SECTION B-B; SECTION D-D; SEZIONE F-F; PESO: 45 g; SCALA:1:1; FOGLIO 1 DI 1; NON SCALARE IL DISEGNO; SBAVATURA E INTERRUZIONE DEI BORDI NETTI; SE NON SPECIFICATO:; FINITURA:

Cava A
relif cut, approxiamate size

QUOTE IN MILLIMETRI
FINITURA SUPERFICIE:
TOLLERANZE:
LINEARE:
ANGOLARE:

NOME | FIRMA | DATA | | | | TITOLO: Tappo Frontale
QUALITA' | | | | MATERIALE: ABS | Disegno 3 N. DISEGNO | A4

DISEGNATO
VERIFICATO
APPROVATO
FATTO

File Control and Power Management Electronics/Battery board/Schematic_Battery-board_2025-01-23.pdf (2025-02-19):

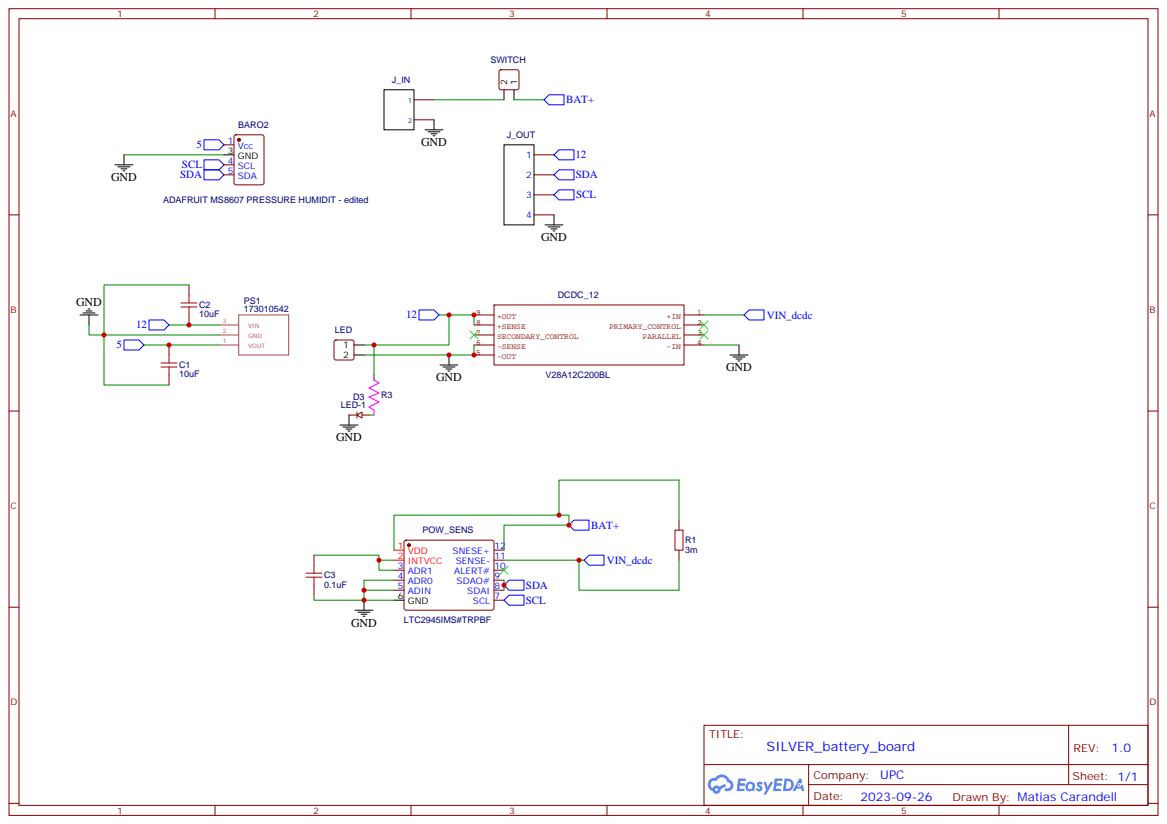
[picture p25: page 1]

ADAFRUIT MS8607 PRESSURE HUMIDIT - edited

Drawn By: Matias Carandell

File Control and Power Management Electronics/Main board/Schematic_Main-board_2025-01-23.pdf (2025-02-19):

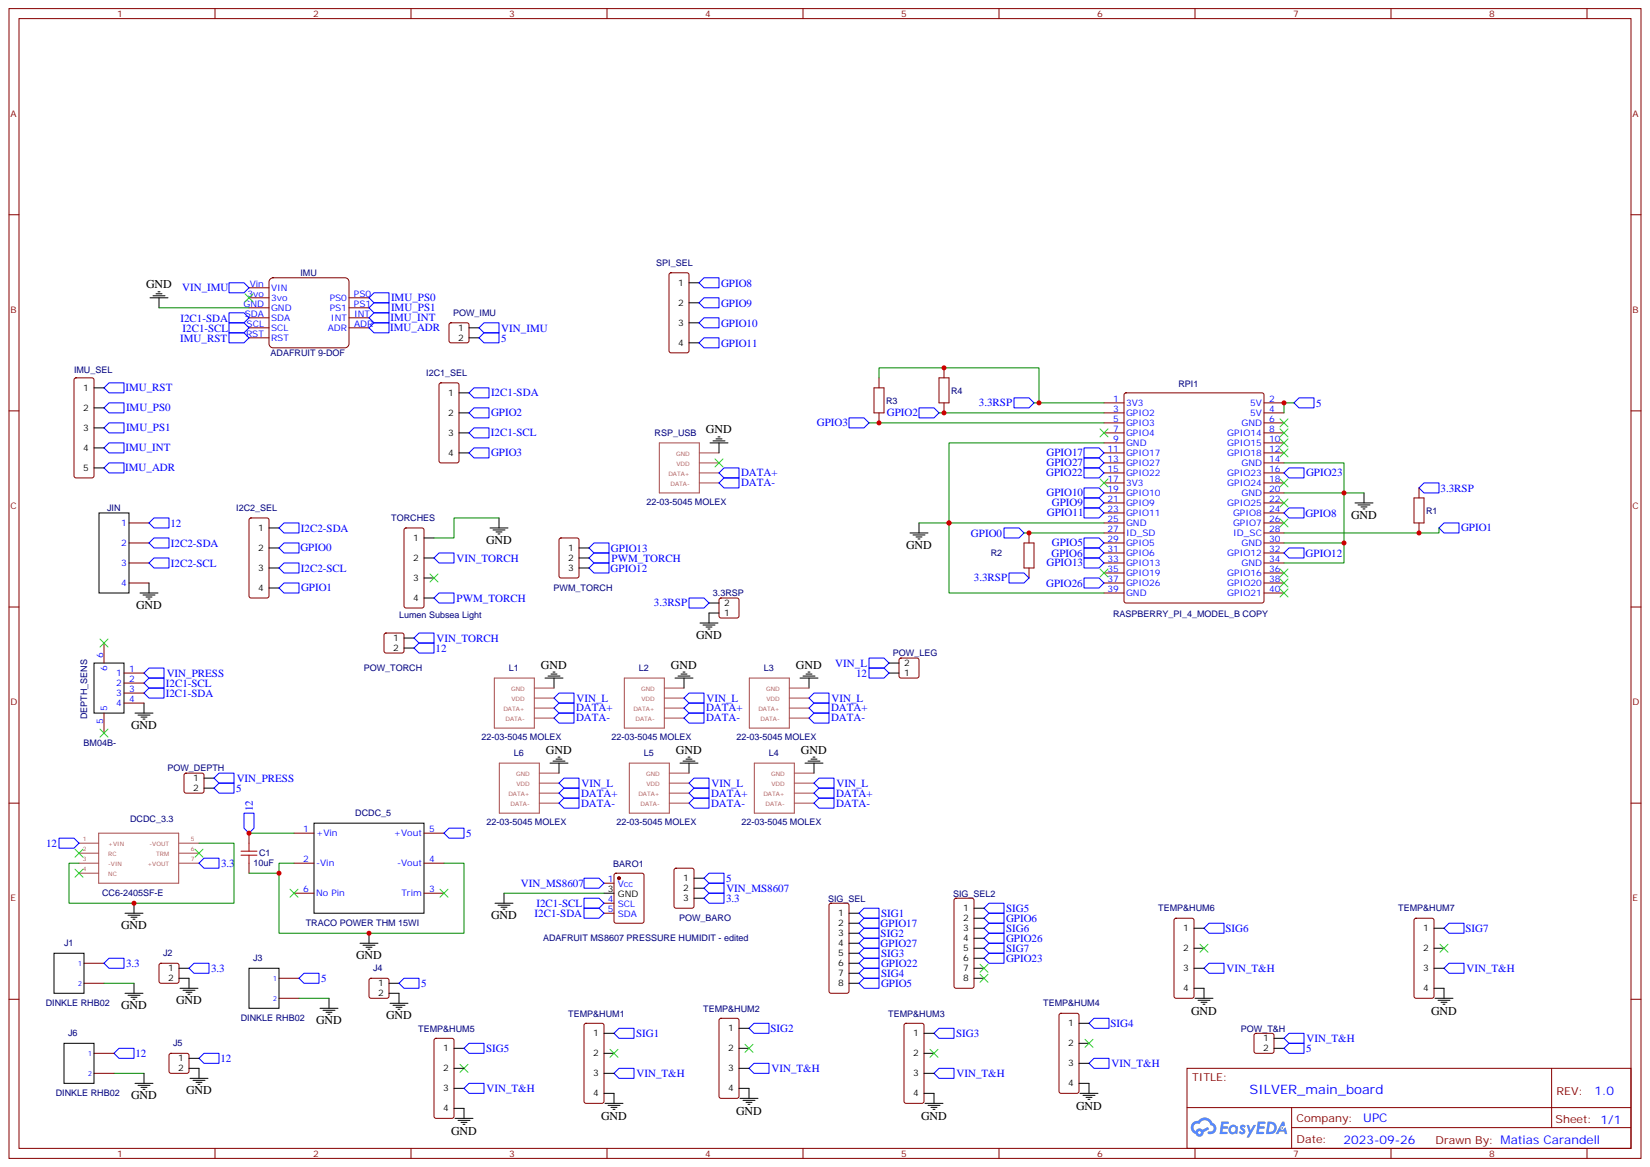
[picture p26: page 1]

VIN Vin
SCL SCL SDA SDA GND GND 3vo 3vo

ADAFRUIT MS8607 PRESSURE HUMIDIT - edited

Drawn By: Matias Carandell

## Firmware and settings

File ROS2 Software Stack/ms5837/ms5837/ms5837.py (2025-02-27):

#!/usr/bin/python
import rclpy
from rclpy.node import Node
from std_msgs.msg import Float64

from .ms5837api import *
import time

class Ms5837Node(Node):
    
    def __init__(self, bus=1):        
        #create sensor object on selected bus
        self.sensor = MS5837_30BA(bus)
        self.sensor.init()
        self.sensor.setFluidDensity(DENSITY_SALTWATER)

        if not self.sensor.read():
            print("Sensor read failed!")
            exit(1)

        # Initialize parent (ROS Node)
        super().__init__('ms5837')
        self.pressure_publisher_ = self.create_publisher(Float64, '/ms5837/pressure', 10)
        self.temperature_publisher_ = self.create_publisher(Float64, '/ms5837/temperature', 10)
        self.depth_publisher_ = self.create_publisher(Float64, '/ms5837/depth', 10)
        timer_period = 0.5
        self.timer = self.create_timer(timer_period, self.timer_callback)
        self.i = 0

        self.get_logger().info("Sensor MS5837 on bus i2c-1 correctly initialized.")

    def timer_callback(self):
        pressure_msg = Float64()
        temperature_msg = Float64()
        depth_msg = Float64()

        try:
            self.sensor.read()
            pressure_msg.data = self.sensor.pressure()
            temperature_msg.data = self.sensor.temperature()
            depth_msg.data = self.sensor.depth()

            self.pressure_publisher_.publish(pressure_msg)
            self.temperature_publisher_.publish(temperature_msg)
            self.depth_publisher_.publish(depth_msg)
            
            self.i +=1
        except:
            self.i +=1


        """self.get_logger().info("Publishing Pressure: %.2f mbar" %pressure_msg.data)
        self.get_logger().info("Publishing Temperature: %.2f C" %temperature_msg.data)
        self.get_logger().info("Publishing Depth in Saltwater: %.7f m" %depth_msg.data)"""

def main(args=None):
    rclpy.init(args=args)
    ms5837_publisher = Ms5837Node()
    rclpy.spin(ms5837_publisher)

    ms5837_publisher.destroy_node()
    rclpy.shutdown()


if __name__ == '__main__':
    main()

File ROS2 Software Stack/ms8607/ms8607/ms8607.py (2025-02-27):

import rclpy
from rclpy.node import Node

from std_msgs.msg import Float64

from time import sleep
import board
from adafruit_ms8607 import MS8607

class Ms8607Node(Node):

	def __init__(self):
		# Create i2c and sensor objects
		self.i2c = board.I2C()
		self.sensor = MS8607(self.i2c)
		
		# Initialize parent (ROS Node)
		super().__init__('ms8607')
		self.pressure_publisher_ = self.create_publisher(Float64, '/ms8607/pressure', 10)
		self.temperature_publisher_ = self.create_publisher(Float64, '/ms8607/temperature', 10)
		self.humidity_publisher_ = self.create_publisher(Float64, '/ms8607/humidity', 10)
		timer_period = 0.5
		self.timer = self.create_timer(timer_period, self.timer_callback)
		self.i = 0
		
	def timer_callback(self):
		pressure_msg = Float64()
		pressure_msg.data = self.sensor.pressure
		
		temperature_msg = Float64()
		temperature_msg.data = self.sensor.temperature
		
		humidity_msg = Float64()
		humidity_msg.data = self.sensor.relative_humidity
		
		self.pressure_publisher_.publish(pressure_msg)
		self.temperature_publisher_.publish(temperature_msg)
		self.humidity_publisher_.publish(humidity_msg)
		
		#self.get_logger().info("Publishing Pressure: %.2f" %pressure_msg.data)
		#self.get_logger().info("Publishing Temperature: %.2f" %temperature_msg.data)
		#self.get_logger().info("Publishing Humidity: %.2f" %humidity_msg.data)
		self.i +=1

def main(args=None):
	rclpy.init(args=args)
	ms8607_publisher = Ms8607Node()
	rclpy.spin(ms8607_publisher)
	
	ms8607_publisher.destroy_node()
	rclpy.shutdown()
	
if __name__ == '__main__':
	main()

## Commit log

2025-02-19 Add Control and Power Management Electronics
    [BOM_Battery-board_2025-01-23.csv, BOM_Main-board_2025-01-23.csv]
2025-02-19 Add Underwater robotic joint manufacturing files
    [CannisterV1_new_version.SLDASM, M2o5x10.SLDPRT, M2o5x20.SLDPRT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]
2025-02-20 Init silver raspy branch
    [colors_rviz.xacro, gaz_ros2_control_use_sim.yaml, gazebo_control.xacro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]
2025-02-20 Update silver directories
    [colors_rviz.xacro, gaz_ros2_control_use_sim.yaml, gazebo_control.xacro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]
2025-02-20 Rename to Silver Workspace
    [colors_rviz.xacro, gaz_ros2_control_use_sim.yaml, gazebo_control.xacro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]
2025-02-21 Updated Sensor Nodes and Documentation
2025-02-26 Update manipulators, controllers and launch files
    [colors_rviz.xacro, gaz_ros2_control_use_sim.yaml, gazebo_control.xacro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]
2025-02-27 modifications to actuators and main launch
    [inertial_macros.xacro, rrr_controllers.yaml, rrr_manipulator.xacro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]
